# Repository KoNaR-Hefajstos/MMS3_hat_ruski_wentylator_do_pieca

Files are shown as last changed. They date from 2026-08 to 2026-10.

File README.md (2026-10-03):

# Hat ruski wentylator do pieca

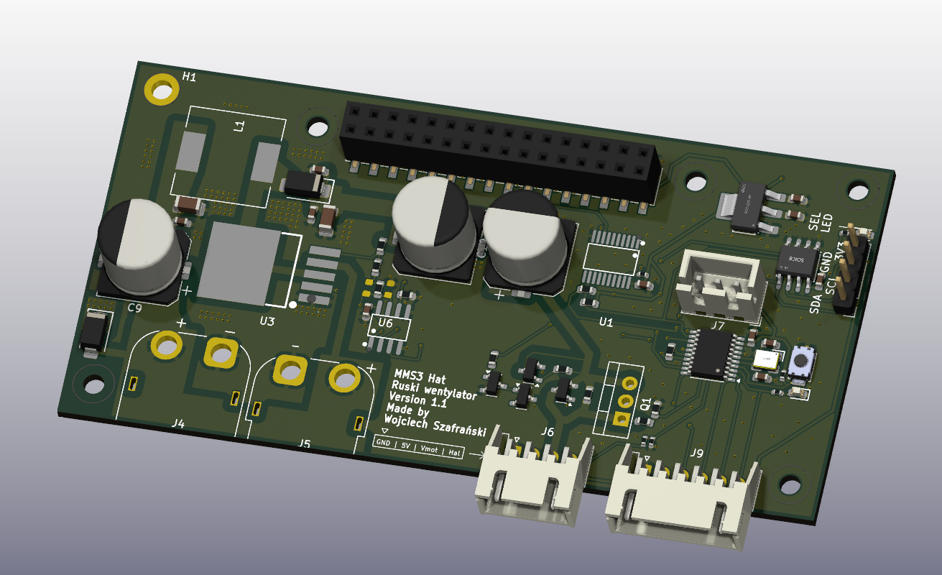
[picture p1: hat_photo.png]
zdjecie


## Sekcja 1: Dokumentacja Hat'a

### Krótki opis projektu
Dedykowany moduł sterujący przeznaczony do obsługi ruskiego wentylatora pieca . Urządzenie bazuje na mikrokontrolerze **CH32V003**, który realizuje zadania regulacji napięcia zasilania silnika, sterowania kluczem PWM, pomiaru prędkości obrotowej z czujnika Halla i reguluje prędkość obrotową przy użyciu regulatora PID.

Moduł wyposażono w przetwornicę podwyższającą (Boost) sterowaną cyfrowym potencjometrem MCP4161 oraz stopień wykonawczy typu **high-side switch** oparty na tranzystorze PMOS.

Komunikacja po I2C

### Zgodność ze standardem ChainBus

* ✅  Używa złącza ChainBus, nie zmienia jego miejsca ani pinoutu.
* ✅  Używa wyłącznie interfejsów I2C, SPI lub UART i nie inicjuje samodzielnie nowych transmisji (Nie jest master'em I2C albo SPI).
* ✅  Spełnia wymagania mechaniczne standardu (wymiary PCB, rozstaw otworów).
* ✅  Pobiera maksymalny prąd zgodny z ilością na jednego hat'a
* ❌ Obsługuje napięcie wejściowe BRD_VIN do wartości 48V. ---> napięcie wejściowe max 40V. Zawsze podaje napięcie wejściowe na wyjście wentylatora (J6 pin 3)

### Komunikacja i adresowanie

#### Adresacja I2C
Komunikacja z płytą główną ChainBus odbywa się za pośrednictwem magistrali I2C podłączonej do mikrokontrolera CH32V003.

| Układ (IC) | Funkcja | Adres I2C (7-bit) |
| :--- | :--- | :---: |
| **CH32V003** | Mikrokontroler (zarządzanie modułem) | *Konfigurowalny w sofcie* |

### Pinout mikrokontrolera CH32V003

| Pin MCU | Nazwa sygnału | Kierunek | Opis funkcjonalny |
| :--- | :--- | :---: | :--- |
| **PC0** | `PWM_GATE` | Wyjście  | Sterowanie bramką PMOS (high-side switch) |
| **PC1** | `SDA` | Wej/Wyj  | Linia danych magistrali I2C (ChainBus) |
| **PC2** | `SCL` | Wejście  | Linia zegarowa magistrali I2C (ChainBus) |
| **PC3** | `BOOST_EN` | Wyjście  | Włączenie przetwornicy Boost (`1` = ON, `0` = OFF) |
| **PC4** | `V_MONITOR` | Wejście  | Pomiar ADC napięcia silnika (dzielnik 36k / 2k) |
| **PC5** | `SPI_SCK` | Wyjście  | Zegar SPI do potencjometru MCP4161 |
| **PC6** | `SPI_MOSI` | Wyjście  | Dane wyjściowe SPI do potencjometru MCP4161 |
| **PC7** | `SPI_MISO` | Wejście  | Dane wejściowe SPI z potencjometru MCP4161 |
| **PD0** | `HALL_INPUT`  | Wejście  | Sygnał z czujnika Halla wentylatora |
| **PD2** | `SPI_CS_POT`  | Wyjście  | Wybór układu (Chip Select) dla MCP4161 |
| **PD3** | `GPIO_PD3` | Wej/Wyj  | Wolny pin GPIO wyprowadzony na złącze J9 |
| **PD4** | `GPIO_PD4` | Wej/Wyj  | Wolny pin GPIO wyprowadzony na złącze J9 |
| **PD5** | `USART_TX` | Wyjście  | Port szeregowy TX (debugowanie, złącze J9) |
| **PD6** | `USART_RX` | Wejście  | Port szeregowy RX (złącze J9) |

---

### Pinout złączy zewnętrznych

#### J6 — Złącze wentylatora pieca
Złącze przeznaczone do bezpośredniego podłączenia ruskiego wentylatora.

| Pin złącza | Kolor przewodu z wentlatora | Nazwa sygnału | Opis |
| :---: | :--- | :--- | :--- |
| **1** | Czarny | `GND` | Wspólna masa układu |
| **2** | Brązowy | `5V` | Zasilanie układu Halla wentylatora |
| **3** | Niebieski | `VCC_MOTOR` | Napięcie zasilające silnik wentylatora |
| **4** | Biały/Żółty | `HALL` | Wyjście czujnika Halla (sprzężenie zwrotne obrotów) |

#### J9 — Złącze wolnych pinów mcu

| Pin złącza | Sygnał | Opis |
| :---: | :----- | :--- |
| **1** | `GND`  | Masa układu |
| **2** | `3V3`  | Zasilanie logiki 3.3V |
| **3** | `PD3`  | Wolny port GPIO |
| **4** | `PD4`  | Wolny port GPIO |
| **5** | `PD5`  | GPIO + Wyjście USART TX |
| **6** | `PD6`  | GPIO + Wejście USART RX |

---

### Konfiguracja i zasada działania stopni wykonawczych

#### 1. Regulacja Napięcia (Przetwornica Boost)
Napięcie zasilania silnika jest generowane przez przetwornicę podwyższającą z poziomu wejściowego 12V. Napięcie wyjściowe regulowane jest przy użyciu potencjometru cyfrowego MCP4161 (5kΩ) działającego jako rezystor nastawny w feedback'u regulatora . Wyjście `P0B` podłączone jest z jednej strony, natomiast wyjścia `P0W` i `P0A` są ze sobą zwarte z drugiej.

Napięcie wyjściowe definiuje zależność:
$$U_{out} = 1.25 \times \left(1 + \frac{50\text{k}\Omega}{1.22\text{k}\Omega + R_{trim}}\right)$$

*   **⚠️ KRYTYCZNE OGRANICZENIE BEZPIECZEŃSTWA:** Mimo teoretycznego zakresu regulacji przetwornicy od 12V do 60V, **maksymalne dopuszczalne napięcie robocze wynosi 24V**. Przekroczenie tego progu spowoduje nieodwracalne uszkodzenie wentylatora, kondensatorów filtrujących oraz stopnia high-side switch. (24V silnika, a ~40V kondensatorów)
*   **Procedura bezpiecznego startu:** Przy każdym uruchomieniu mikrokontrolera, oprogramowanie musi natychmiast ustawić potencjometr MCP4161 na **maksymalną rezystancję (5kΩ)**, co wymusza minimalne napięcie startowe (ok. 11.3V). Dodatkowo, przetwornica Boost oraz klucz PWM muszą być domyślnie wyłączone (`BOOST_EN` = `0`, `PWM_GATE` = `0`).
*   **Charakterystyka Boost:** Nawet w stanie wyłączonym (`BOOST_EN` = `0`), napięcie wejściowe 12V będzie stale obecne na wyjściu przetwornicy.

#### 2. Bonusowy Stopień wykonawczy (High-Side Switch PMOS)
Sterowanie dopływem prądu z przetwornicy do silnika wentylatora odbywa się za pomocą klucza high-side switch opartego na tranzystorze PMOS.

*   **Konfiguracja domyślna (Bypass):** Na płycie fabrycznie wlutowany jest rezystor **R6**, który zwiera (pomija) tranzystor PMOS. W tym trybie silnik zasilany jest stale bezpośrednio z wyjścia przetwornicy Boost, a regulacja obrotów odbywa się wyłącznie poprzez zmianę jej napięcia wyjściowego.
*   **Konfiguracja zaawansowana (Sterowanie PWM):** W celu sterowania silnikiem za pomocą cięcia prądu sygnałem PWM z pinu `PC0` mikrokontrolera, należy **odlutować rezystor R6**.
*   **Element wykonawczy:** Na płycie domyślnie znajduje się tranzystor PMOS **AO3401A** (obudowa SOT-23, parametry: 30V, 4A), który jest w pełni wystarczający do obsługi docelowego wentylatora piecowego. Na laminacie pozostawiono jednak alternatywne, wolne miejsce na montaż mocniejszego tranzystora w obudowie **TO-220** na wypadek nietypowych modyfikacji.

#### A po ludzku
* Masz wentlator, sterujesz jego prękością dając mu różne napięcie i/lub PWM
* Napięciem sterujesz przez potencjometr cyfrowy
* PWM przez high side switch (który jest domyślnie z'bypass'owany czyli trzeba wylutować rezystor żeby go użyć)
* Przetworke możesz właczyć/wyłączyć, ale zawsze daje VIN na wyjście silnika
* Prędkość obrotową wentylatora możesz odczytać przez częstotliwosć impulsów na czujnika halla
* A napięcie wyjściowe przetworki jest po dzielniku napięć na pin'ie PC4 (dzielnik dzieli VCC silnika przez 18)

---

### Gotowe arkusze hierarchiczne
W projekcie zaprojektowano i użyto następujących arkuszy hierarchicznych:
* **CH32v003** – Schemat mikrokontrolera głównego wraz z elementami pasywnymi i złączem programowania
* **Boost converter** – Układ regulowanej przetwornicy podwyższającej napięcie z 12V na zakres do ~60V sterowanej cyfrowym potencjometrem MCP4161.
* **High side switch** – Blok High-side switch'a na PMOS (AO3401A) sterowanego sygnałem PWM z układem typu totem pole do drive'owania bramki
---

## Sekcja 2: Specyfikacja standardu ChainBus

### Architektura i łączenie modułów
Standard ChainBus umożliwia modułowe łączenie hatów. Na jednym MMS3 można zamontować pionowo **do 8 hat'ów**. Połączenie realizowane jest poprzez wpięcie złącza męskiego kolejnego hat'a w złącze żeńskie poprzedniego

### Komunikacja i sterowanie
Magistrala ChainBus jest w pełni cyfrowa. Płyta główna nie steruje bezpośrednio sygnałami ogólnego przeznaczenia (GPIO) na poszczególnych hat'ach. Wszelkie operacje (np. obsługa diod LED, odczyt krańcówek, generowanie sygnałów PWM) muszą być realizowane przez dedykowane układy scalone (np. ekspandery portów, sterowniki) komunikujące się przez interfejsy systemowe.

*Przykład:*
`MCU` $\rightarrow$ `Expander GPIO po I2C` $\rightarrow$ `Dioda LED`

Wybór aktywnego modułu realizowany jest przez układ przełącznika magistrali (bus switch) na płycie głównej. Dzięki temu linie I2C, SPI i UART są niezależne dla każdego hat'a (brak konfliktów adresów I2C między różnymi hatami).
* **Identyfikacja:** Każdy moduł powinien posiadać pamięć EEPROM na magistrali I2C w celu identyfikacji płyty przez system - układ M24C64-W skonfigurowany na adres `1010000` przy liniach adresowych A0, A1, A2 zwartych do masy.

### Zasilanie
Złącze ChainBus dostarcza następujące linie zasilania:

| Magistrala zasilania | Napięcie znamionowe | Maksymalny prąd (łączny dla 8 hatów) | Szacowany prąd na jeden hat |
| :--- | :---: | :---: | :---: |
| **5V** | 5.0 V | 1.0 A | 125 mA |
| **12V stby** | 12.0 V | 0.5 A | 65 mA |
| **BRD_VIN** | 12.0 V – 48.0 V | 1.5 A | 185 mA |

*   Komponenty podłączone do linii `BRD_VIN` muszą być przystosowane do pracy z napięciem od 12V do **48 V**.
*   W przypadku zapotrzebowania na wyższą moc, dopuszczalne jest zastosowanie dodatkowego złącza zasilania XT60 (obciążalność do ok. 60 A).

### Wymagania mechaniczne i złącza
* **Wymiary PCB:** Niedozwolona jest zmiana obrysu płytki oraz położenia otworów montażowych, aby zachować kompatybilność mechaniczną.
* **Pozycjonowanie złączy ChainBus:** Położenie złącza standardu 2x16 SMD (raster 2.54 mm) musi być zgodne z szablonem. Złącze żeńskie montowane jest na stronie FRONT, natomiast złącze męskie na stronie BACK.
* **Interfejsy zewnętrzne:** Złącza wejścia/wyjścia (domyślnie standard JST-XH 2.5 mm o obciążalności do 3 A) oraz opcjonalne złącze XT60 powinny być umieszczone przy dolnej krawędzi płytki. Elementy regulacyjne i sygnalizacyjne (potencjometry, przełączniki, diody LED) należy lokalizować przy prawej krawędzi płytki.
* **Komponenty** Wszystkie komponenty powinny być na stronie front płytki żeby nie haczyły o elementy ze wcześniejszego hat'a

---

## Sekcja 3: Licencje

### Licencje projektu

*   **PCB:** CERN-OHL-P
*   **Software:** MIT License

[Template](https://github.com/KoNaR-Hefajstos/MMS3_hat_templates/) jest na licencji CC0 1.0 Universal. **Reszta projektu nie jest na tej licencji**

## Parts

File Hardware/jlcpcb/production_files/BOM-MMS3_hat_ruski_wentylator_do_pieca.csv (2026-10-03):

Comment | Designator | Footprint | LCSC | Quantity
0Ω | R18,R6 | R_0603 | C21189 | 2
100nF | C1,C2,C4,C6 | C_0603 | C14663 | 4
10kΩ | R12,R19,R24 | R_0402 | C25744 | 3
10kΩ | R2,R3 | R_0603 | C25804 | 2
10uF | C14,C15 | C_1206 | C13585 | 2
10uF | C16,C18 | C_0603 | C19702 | 2
12pF | C3,C5 | C_0603 | C38523 | 2
15kΩ | R23 | R_0402 | C25756 | 1
1kΩ | R16,R17,R5,R7 | R_0603 | C21190 | 4
1uF | C10,C11,C17 | C_0603 | C15849 | 3
220Ω | R28 | R_0603 | C22962 | 1
2kΩ | R20 | R_0603 | C22975 | 1
330Ω | R1,R13 | R_0402 | C25104 | 2
36kΩ | R4 | R_0603 | C23147 | 1
56kΩ | R14 | R_0603 | C23206 | 1
AMS1117 | U4 | SOT-223-3_L6.5-W3.4-P2.30-LS7.0-BR | C6186 | 1
AO3401A | Q10 | Q_SOT-23 | C15127 | 1
M24C64 | U2 | SOIC-8_L5.0-W4.0-P1.27-LS6.0-BL | C79988 | 1
M7 | D1 | D_SMA | C95872 | 1
MCP4161-502E/SN | U6 | SOIC-8_L4.9-W3.9-P1.27-LS6.0-BL | C636080 | 1
MMBT5401 200-300 | Q11 | Q_SOT-23 | C8326 | 1
MMBT5551 200-300 | Q12,Q9 | Q_SOT-23 | C2145 | 2
Red | D3,D5 | D_0603 | C2286 | 2
SN74CB3Q3245PWR | U1 | TSSOP-20_L6.5-W4.4-P0.65-LS6.4-BL | C470961 | 1
SS54 | D2 | D_SMA | C22452 | 1
Tactile Button, 160gf | S1 | SW_TS-1088-AR02016 | C720477 | 1
Whatever the chinese man has (preferably 220uF) | C12,C13,C9 | CP_Elec_10x10 | C178727 | 3
X322525MOB4SI | X2 | OSC-SMD_4P-L3.2-W2.5-BL | C9006 | 1
XL6019E1 | U3 | TO-263-5_L10.2-W9.9-P1.70-LS14.4-TL | C73018 | 1
Conn_01x06_Socket | J9 | JST_XH_S6B-XH-A_1x06_P2.50mm_Horizontal |  | 1
Program | J7 | JST_XH_B3B-XH-A_1x03_P2.50mm_Vertical |  | 1
Conn_01x04_Socket | J6 | JST_XH_S4B-XH-A_1x04_P2.50mm_Horizontal |  | 1
Chainbus Out | J2 | PinSocket_2x16_P2.54mm_Vertical_SMD |  | 1
PMOS | Q1 | TO-220-3_Vertical |  | 1
Conn_01x04_Pin | J3 | PinHeader_1x04_P2.54mm_Vertical |  | 1
47uH 5A | L1 | L_12x12mm_H6mm |  | 1
CH32V003FxPx | U5 | TSSOP-20_4.4x6.5mm_P0.65mm |  | 1
TestPoint | TP5 | TestPoint_Pad_D1.5mm |  | 1
Chainbus in | J1 | PinHeader_2x16_P2.54mm_Vertical_SMD |  | 1
TestPoint | TP4 | TestPoint_Pad_D1.5mm |  | 1
TestPoint | TP6 | TestPoint_Pad_D1.5mm |  | 1

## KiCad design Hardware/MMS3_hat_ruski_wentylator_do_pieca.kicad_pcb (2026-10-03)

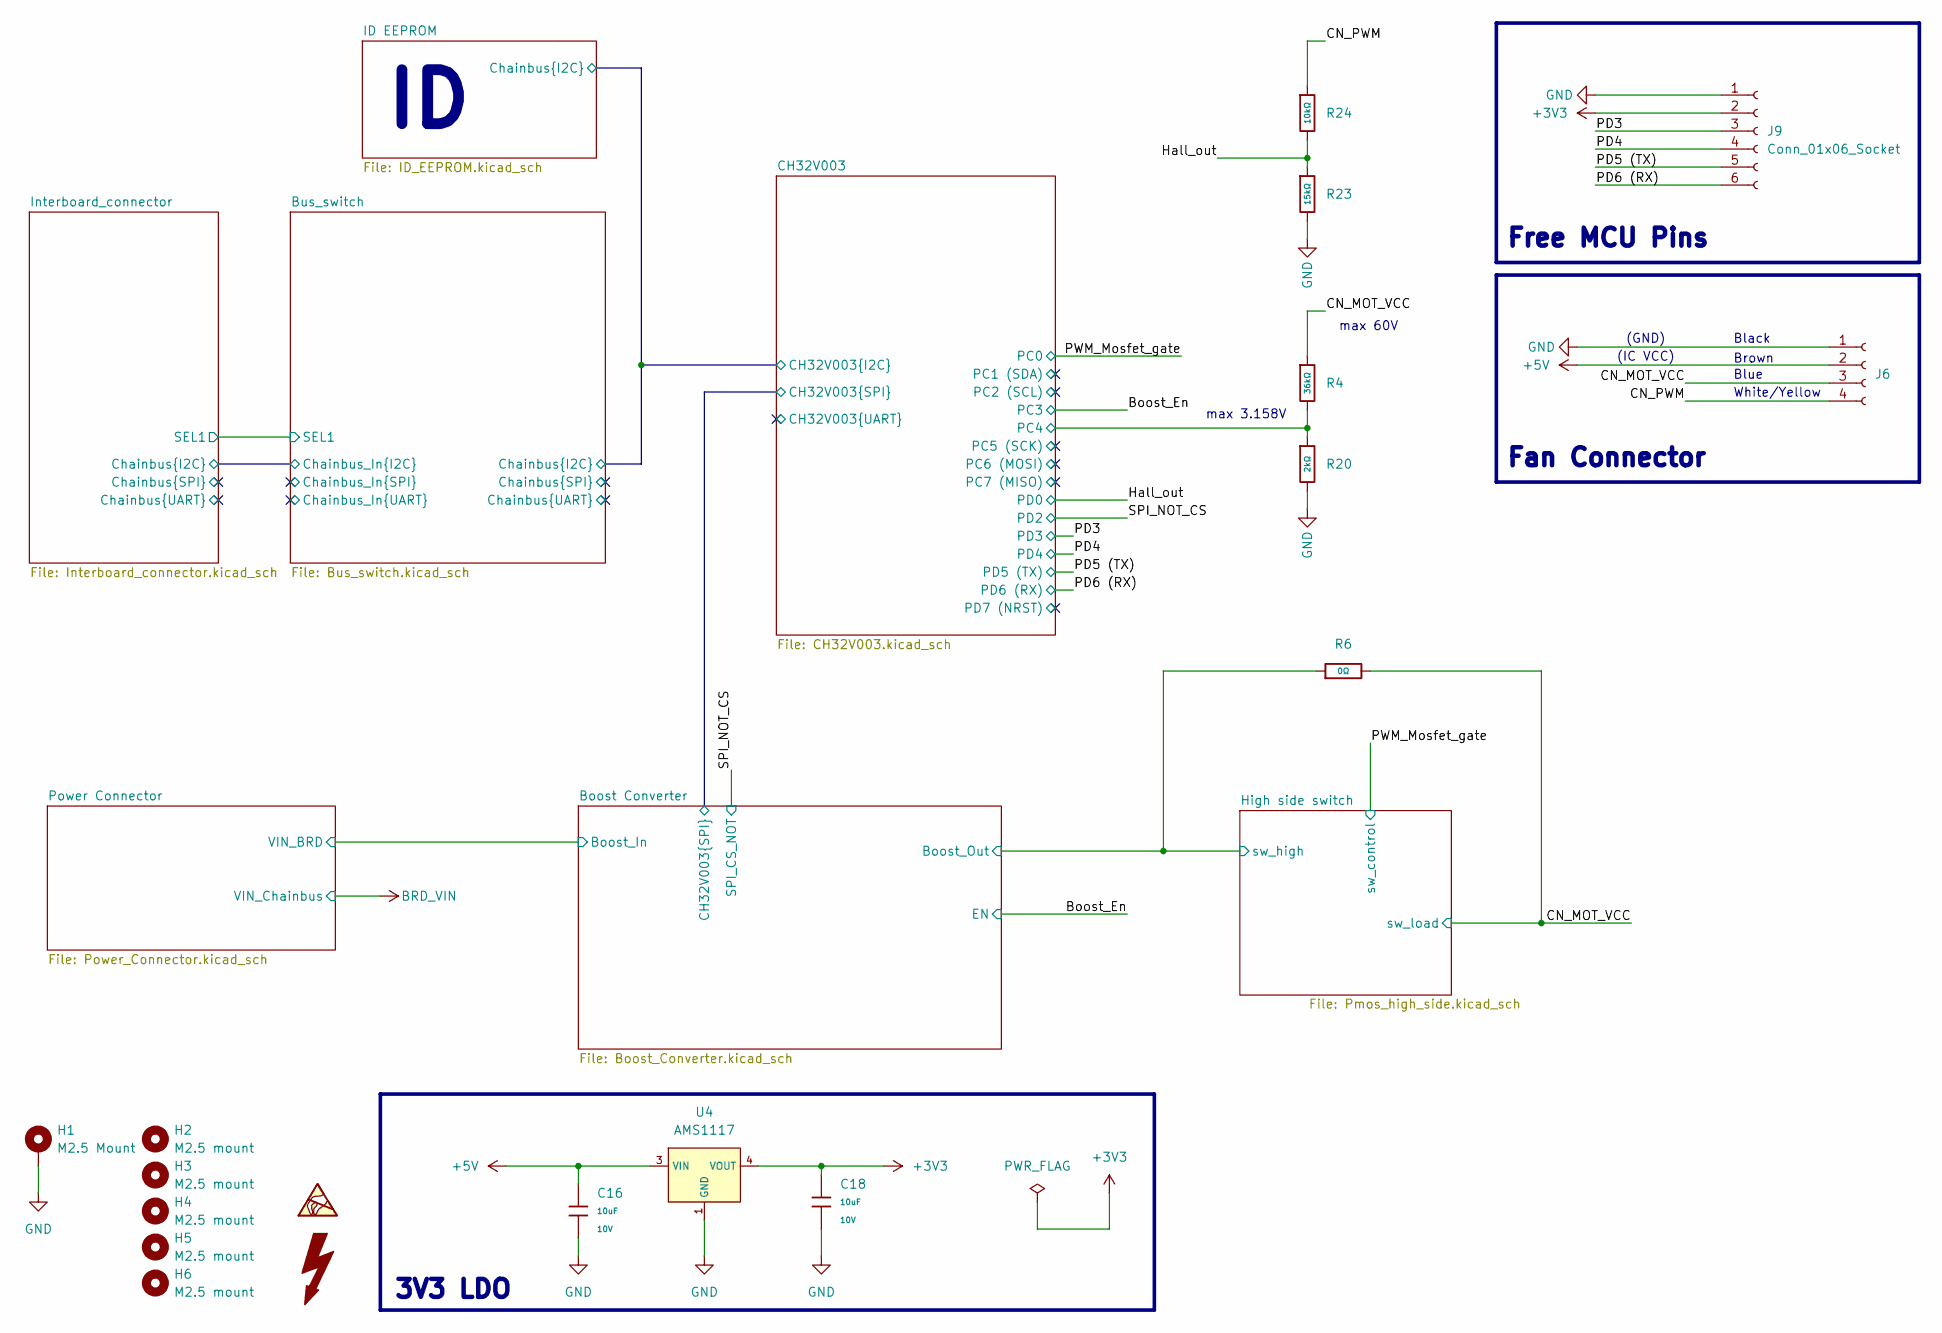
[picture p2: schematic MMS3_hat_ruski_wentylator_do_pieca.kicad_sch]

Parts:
C16, C18: 10uF; C_0603; Voltage Rated 10V; Tolerance ±10%; Part CL10A106KP8NNNC; LCSC C19702
H1: M2.5 Mount; MountingHole_2.7mm_M2.5_DIN965_Pad_TopOnly
H2, H3, H4, H5, H6: M2.5 mount; MountingHole_2.7mm_M2.5
J6: Conn_01x04_Socket; JST_XH_S4B-XH-A_1x04_P2.50mm_Horizontal
J9: Conn_01x06_Socket; JST_XH_S6B-XH-A_1x06_P2.50mm_Horizontal
R4: 36kΩ; R_0603; Overload Voltage (Max) 75V; Tolerance ±1%; Part 0603WAF3602T5E; LCSC C23147
R6: 0Ω; R_0603; Overload Voltage (Max) 75V; Tolerance ±1%; Part 0603WAF0000T5E; LCSC C21189
R20: 2kΩ; R_0603; Overload Voltage (Max) 75V; Tolerance ±1%; Part 0603WAF2001T5E; LCSC C22975
R23: 15kΩ; R_0402; Overload Voltage (Max) 50V; Tolerance ±1%; Part 0402WGF1502TCE; LCSC C25756
R24: 10kΩ; R_0402; Overload Voltage (Max) 50V; Tolerance ±1%; Part 0402WGF1002TCE; LCSC C25744
U4: AMS1117; SOT-223-3_L6.5-W3.4-P2.30-LS7.0-BR; Output Voltage 3.3V; Dropout Voltage 1.3V@(800mA); Part AMS1117-3.3; LCSC C6186

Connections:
+3V3: C18.1, J9.2, U4.2 (VOUT), U4.4 (VOUT); also elsewhere on the board
+5V: C16.1, J6.2, U4.3 (VIN); also elsewhere on the board
/Boost Converter/Boost_Out: R6.1; also elsewhere on the board
/CH32V003/PC4: R4.2, R20.1; also elsewhere on the board
/CN_MOT_VCC: J6.3, R4.1, R6.2; also elsewhere on the board
/CN_PWM: J6.4, R24.1
/Hall_out: R23.1, R24.2; also elsewhere on the board
/PD3: J9.3; also elsewhere on the board
/PD4: J9.4; also elsewhere on the board
/PD5 (TX): J9.5; also elsewhere on the board
/PD6 (RX): J9.6; also elsewhere on the board
GND: C16.2, C18.2, H1.1 (1_1), J6.1, J9.1, R20.2, R23.2, U4.1 (GND); also elsewhere on the board

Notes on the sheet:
(IC VCC)
Blue
max 60V
Fan Connector
White/Yellow
(GND)
3V3 LDO
Free MCU Pins
max 3.158V
Brown
Black

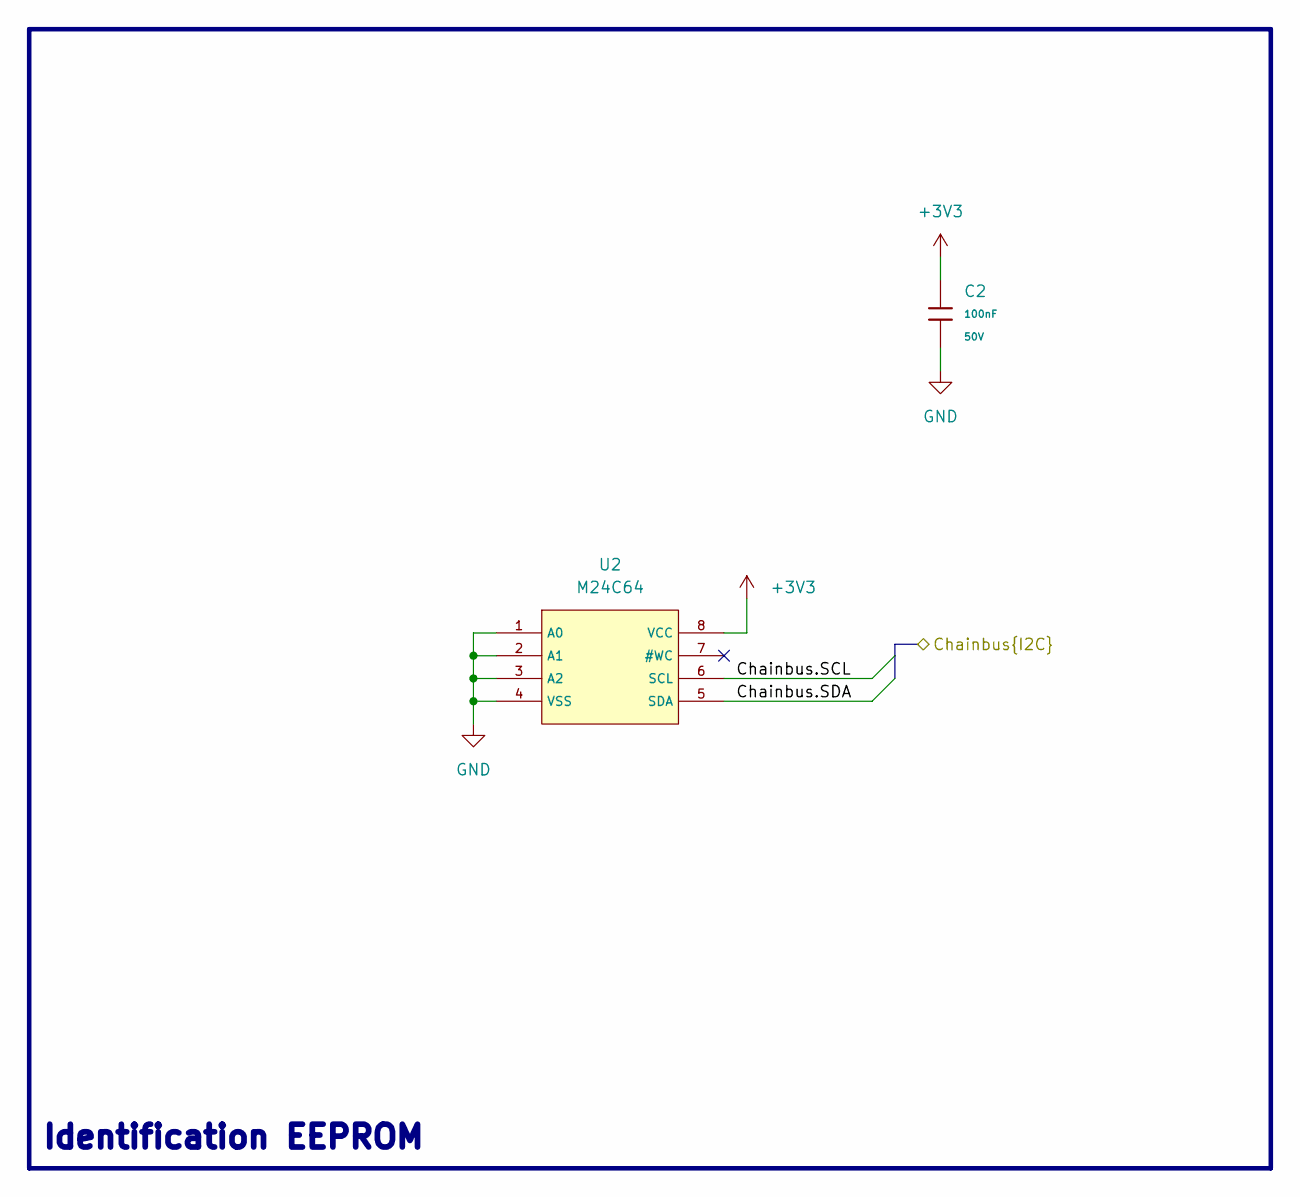
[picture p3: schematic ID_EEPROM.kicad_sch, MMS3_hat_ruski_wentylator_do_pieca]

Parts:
C2: 100nF; C_0603; Voltage Rated 50V; Tolerance ±10%; Part CC0603KRX7R9BB104; LCSC C14663
U2: M24C64; SOIC-8_L5.0-W4.0-P1.27-LS6.0-BL; Supply Voltage 1.8V~5.5V; Part M24C64-RMN6TP; LCSC C79988

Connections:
+3V3: C2.1, U2.8 (VCC); also elsewhere on the board
/Bus_switch/Chainbus.SCL: U2.6 (SCL); also elsewhere on the board
/Bus_switch/Chainbus.SDA: U2.5 (SDA); also elsewhere on the board
GND: C2.2, U2.1 (A0), U2.2 (A1), U2.3 (A2), U2.4 (VSS); also elsewhere on the board

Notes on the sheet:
Identification EEPROM

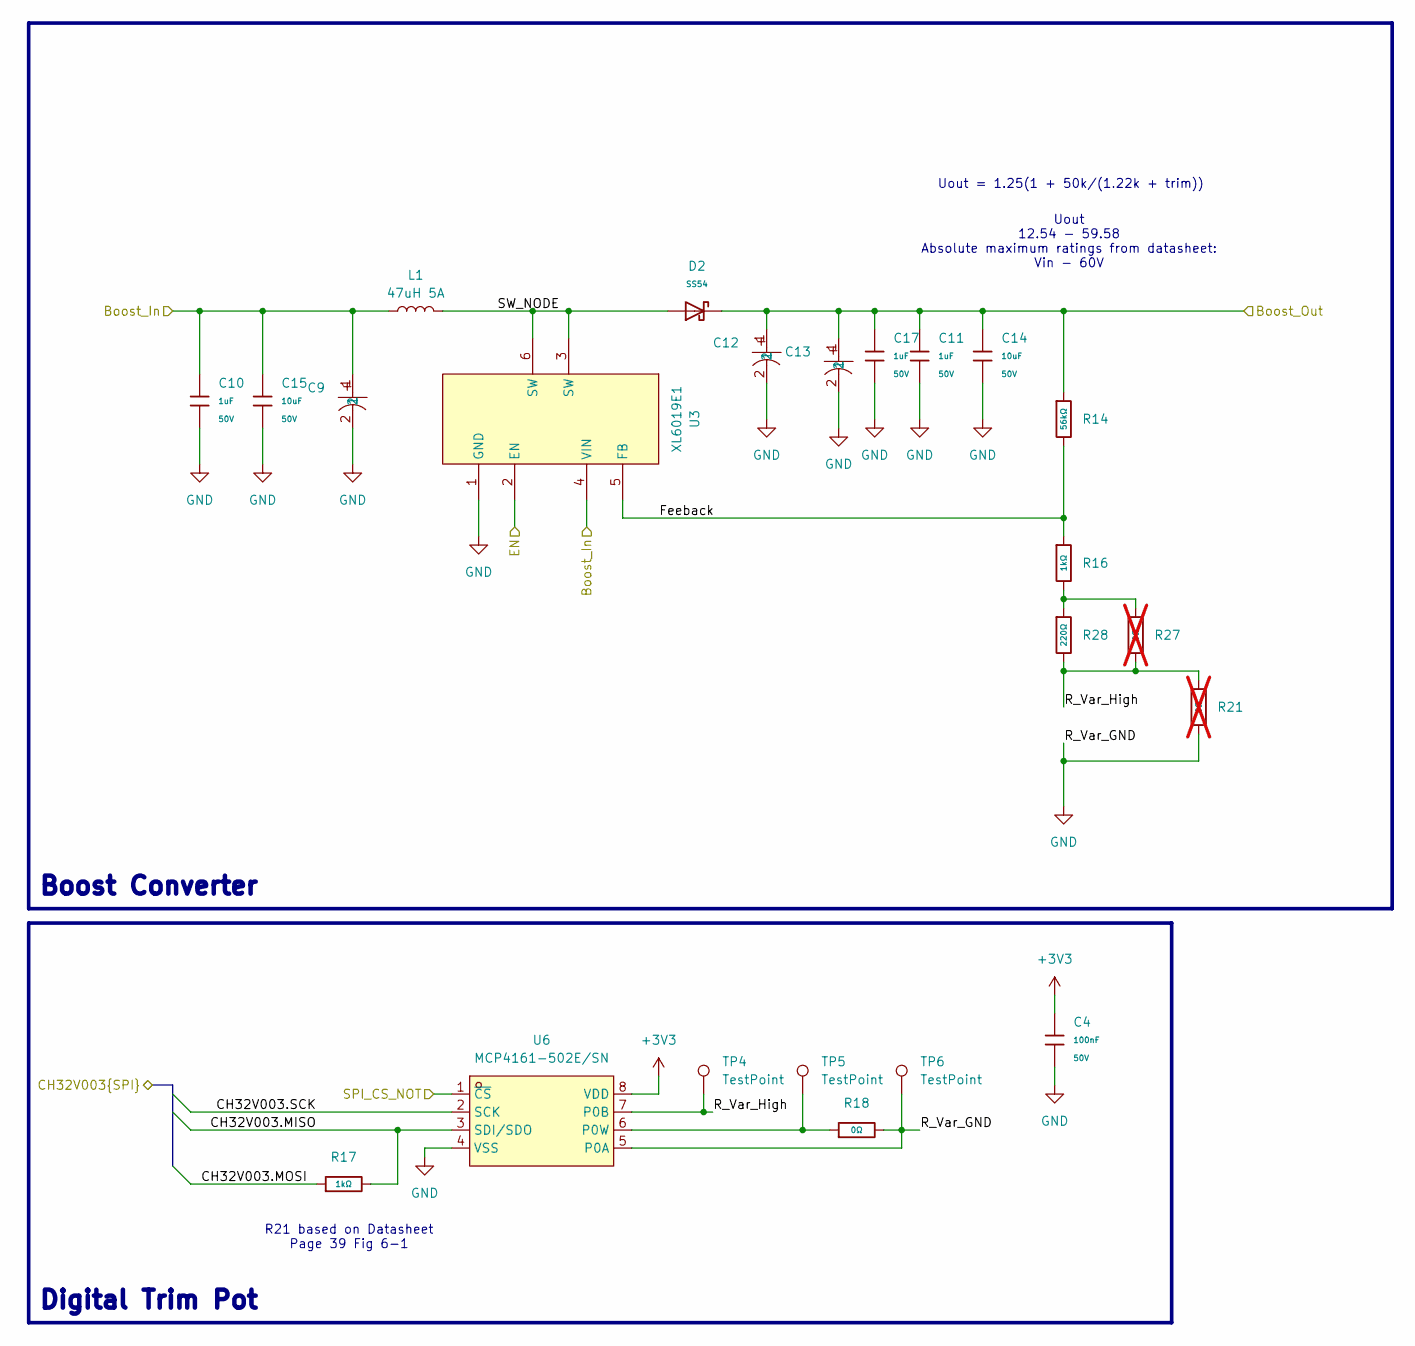
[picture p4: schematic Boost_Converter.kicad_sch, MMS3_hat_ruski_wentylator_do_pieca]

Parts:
C4: 100nF; C_0603; Voltage Rated 50V; Tolerance ±10%; Part CC0603KRX7R9BB104; LCSC C14663
C9, C12, C13: Whatever the chinese man has (preferably 220uF); CP_Elec_10x10; MPN EEVFK1J221Q; LCSC Part C178727
C10, C11, C17: 1uF; C_0603; Voltage Rated 50V; Tolerance ±10%; Part CL10A105KB8NNNC; LCSC C15849
C14, C15: 10uF; C_1206; Voltage Rated 50V; Tolerance ±10%; Part CL31A106KBHNNNE; LCSC C13585
D2: SS54; D_SMA; Forward Voltage (Vf@If) 550mV@5A; Reverse Voltage (Vr) 40V; Part SS54; LCSC C22452
L1: 47uH 5A; L_12x12mm_H6mm
R14: 56kΩ; R_0603; Overload Voltage (Max) 75V; Tolerance ±1%; Part 0603WAF5602T5E; LCSC C23206
R16, R17: 1kΩ; R_0603; Overload Voltage (Max) 75V; Tolerance ±1%; Part 0603WAF1001T5E; LCSC C21190
R18: 0Ω; R_0603; Overload Voltage (Max) 75V; Tolerance ±1%; Part 0603WAF0000T5E; LCSC C21189
R21, R27: 0Ω; R_0603; Overload Voltage (Max) 75V; Tolerance ±1%; Part 0603WAF0000T5E; LCSC C21189; not fitted
R28: 220Ω; R_0603; Overload Voltage (Max) 75V; Tolerance ±1%; Part 0603WAF2200T5E; LCSC C22962
TP4, TP5, TP6: TestPoint; TestPoint_Pad_D1.5mm
U3: XL6019E1; TO-263-5_L10.2-W9.9-P1.70-LS14.4-TL; MPN XL6019E1; LCSC Part C73018
U6: MCP4161-502E/SN; SOIC-8_L4.9-W3.9-P1.27-LS6.0-BL; MPN MCP4161-502E/SN; LCSC Part C636080

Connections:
+3V3: C4.1, U6.8 (VDD); also elsewhere on the board
/Boost Converter/Boost_In: C9.1, C10.1, C15.1, L1.1, U3.4 (VIN); also elsewhere on the board
/Boost Converter/Boost_Out: C11.1, C12.1, C13.1, C14.1, C17.1, D2.1, R14.1; also elsewhere on the board
/Boost Converter/CH32V003.MISO: R17.2, U6.3 (SDI/SDO); also elsewhere on the board
/Boost Converter/CH32V003.MOSI: R17.1; also elsewhere on the board
/Boost Converter/CH32V003.SCK: U6.2 (SCK); also elsewhere on the board
/Boost Converter/Feeback: R14.2, R16.1, U3.5 (FB)
/Boost Converter/R_Var_High: R21.2, R27.1, R28.2, TP4.1 (1_1), U6.7 (P0B)
/Boost Converter/SW_NODE: D2.2, L1.2, U3.3 (SW), U3.6 (SW)
/Boost_En: U3.2 (EN); also elsewhere on the board
/SPI_NOT_CS: U6.1 (~CS); also elsewhere on the board
GND: C4.2, C9.2, C10.2, C11.2, C12.2, C13.2, C14.2, C15.2, C17.2, R18.2, R21.1, TP6.1 (1_1), U3.1 (GND), U6.4 (VSS), U6.5 (P0A); also elsewhere on the board
unnamed: R16.2, R27.2, R28.1
unnamed: R18.1, TP5.1 (1_1), U6.6 (P0W)

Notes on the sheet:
Uout = 1.25(1 + 50k/(1.22k + trim))
Boost Converter
Uout 12.54 - 59.58 Absolute maximum ratings from datasheet: Vin - 60V
R21 based on Datasheet Page 39 Fig 6-1
Digital Trim Pot

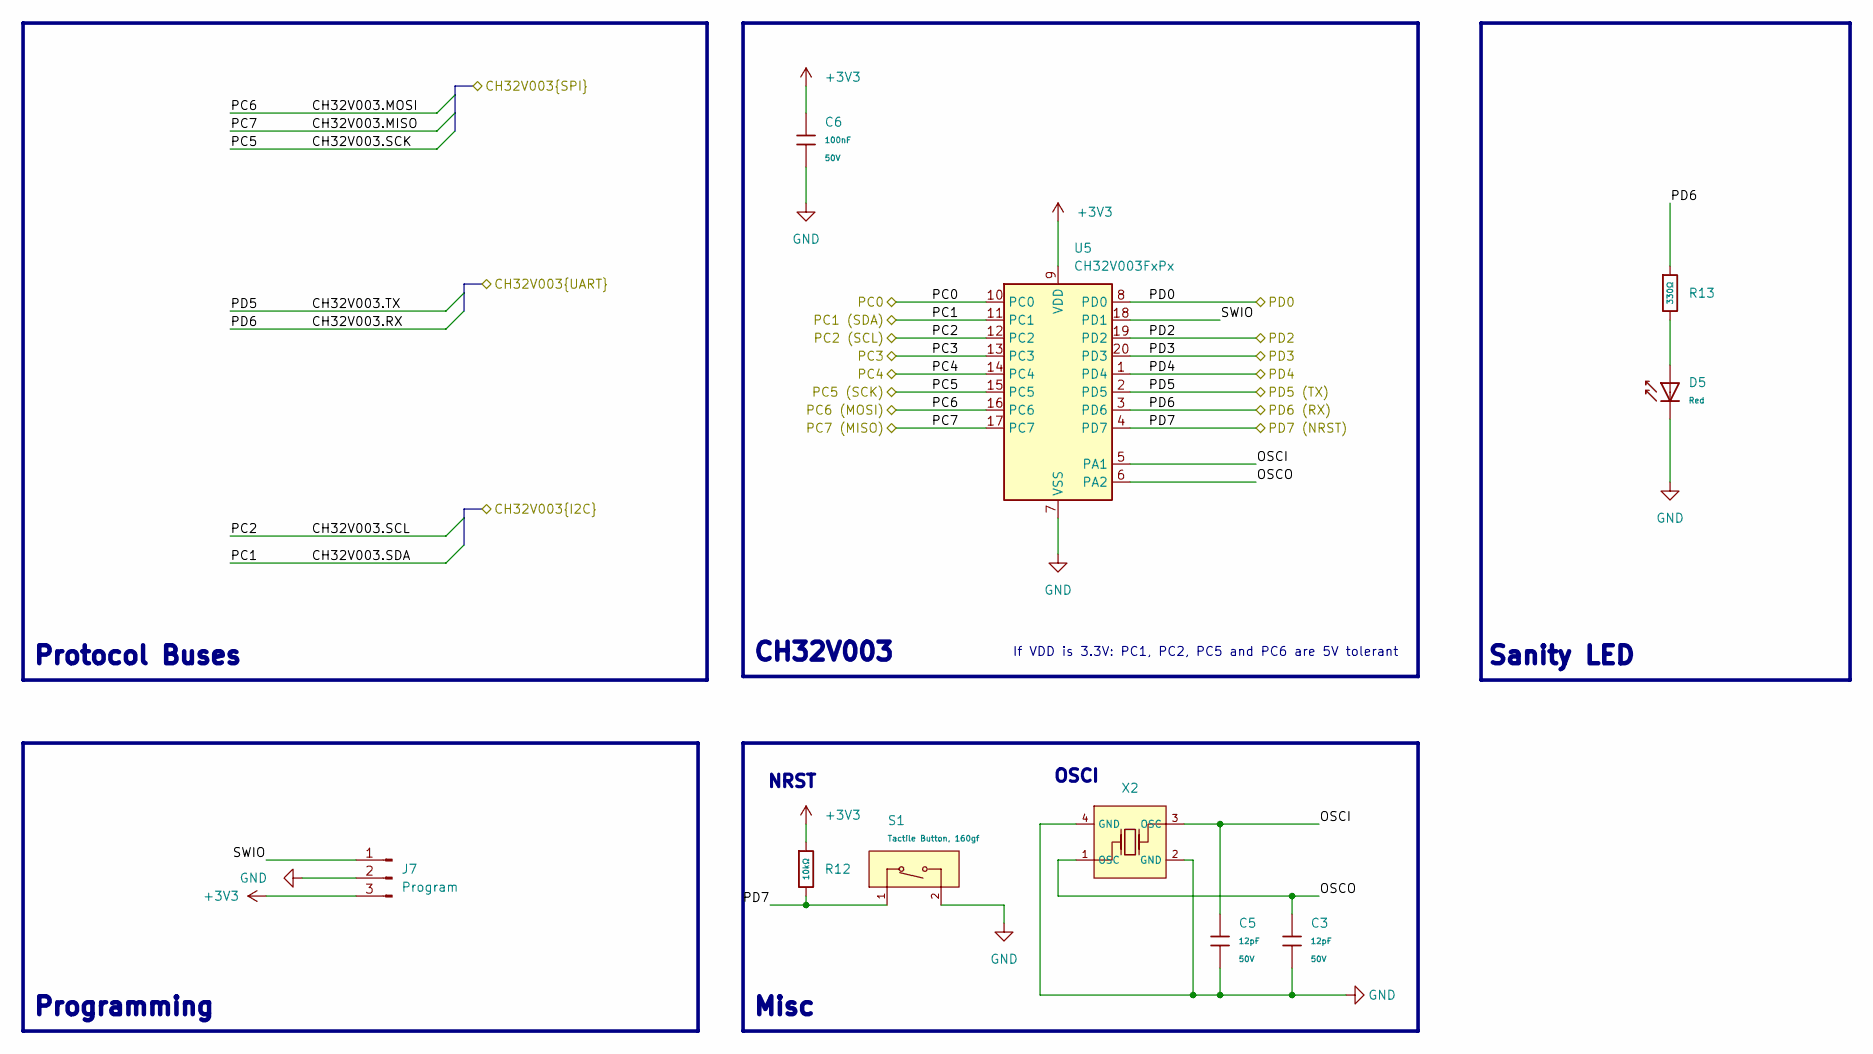
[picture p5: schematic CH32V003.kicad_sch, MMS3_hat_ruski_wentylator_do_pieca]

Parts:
C3, C5: 12pF; C_0603; Voltage Rated 50V; Tolerance ±5%; Part CL10C120JB8NNNC; LCSC C38523
C6: 100nF; C_0603; Voltage Rated 50V; Tolerance ±10%; Part CC0603KRX7R9BB104; LCSC C14663
D5: Red; D_0603; Part KT-0603R; LCSC C2286
J7: Program; JST_XH_B3B-XH-A_1x03_P2.50mm_Vertical
R12: 10kΩ; R_0402; Overload Voltage (Max) 50V; Tolerance ±1%; Part 0402WGF1002TCE; LCSC C25744
R13: 330Ω; R_0402; Overload Voltage (Max) 50V; Tolerance ±1%; Part 0402WGF3300TCE; LCSC C25104
S1: Tactile Button, 160gf; SW_TS-1088-AR02016; Voltage Rating (Dc) 12V; Part TS-1088-AR02016; LCSC C720477
U5: CH32V003FxPx; TSSOP-20_4.4x6.5mm_P0.65mm
X2: X322525MOB4SI; OSC-SMD_4P-L3.2-W2.5-BL; Frequency Tolerance ±10ppm; Part X322525MOB4SI; LCSC C9006

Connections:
+3V3: C6.1, J7.3, R12.1, U5.9 (VDD); also elsewhere on the board
/Boost Converter/CH32V003.MISO: U5.17 (PC7); also elsewhere on the board
/Boost Converter/CH32V003.MOSI: U5.16 (PC6); also elsewhere on the board
/Boost Converter/CH32V003.SCK: U5.15 (PC5); also elsewhere on the board
/Boost_En: U5.13 (PC3); also elsewhere on the board
/Bus_switch/Chainbus.SCL: U5.12 (PC2); also elsewhere on the board
/Bus_switch/Chainbus.SDA: U5.11 (PC1); also elsewhere on the board
/CH32V003/OSCI: C5.1, U5.5 (PA1), X2.3 (OSC)
/CH32V003/OSCO: C3.1, U5.6 (PA2), X2.1 (OSC)
/CH32V003/PC4: U5.14 (PC4); also elsewhere on the board
/CH32V003/PD7: R12.2, S1.1 (A), U5.4 (PD7)
/CH32V003/SWIO: J7.1, U5.18 (PD1)
/Hall_out: U5.8 (PD0); also elsewhere on the board
/PD3: U5.20 (PD3); also elsewhere on the board
/PD4: U5.1 (PD4); also elsewhere on the board
/PD5 (TX): U5.2 (PD5); also elsewhere on the board
/PD6 (RX): R13.1, U5.3 (PD6); also elsewhere on the board
/PWM_Mosfet_gate: U5.10 (PC0); also elsewhere on the board
/SPI_NOT_CS: U5.19 (PD2); also elsewhere on the board
GND: C3.2, C5.2, C6.2, D5.1, J7.2, S1.2 (B), U5.7 (VSS), X2.2 (GND), X2.4 (GND); also elsewhere on the board
unnamed: D5.2, R13.2

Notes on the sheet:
NRST
Sanity LED
If VDD is 3.3V: PC1, PC2, PC5 and PC6 are 5V tolerant
CH32V003
OSCI
Protocol Buses
Misc
Programming

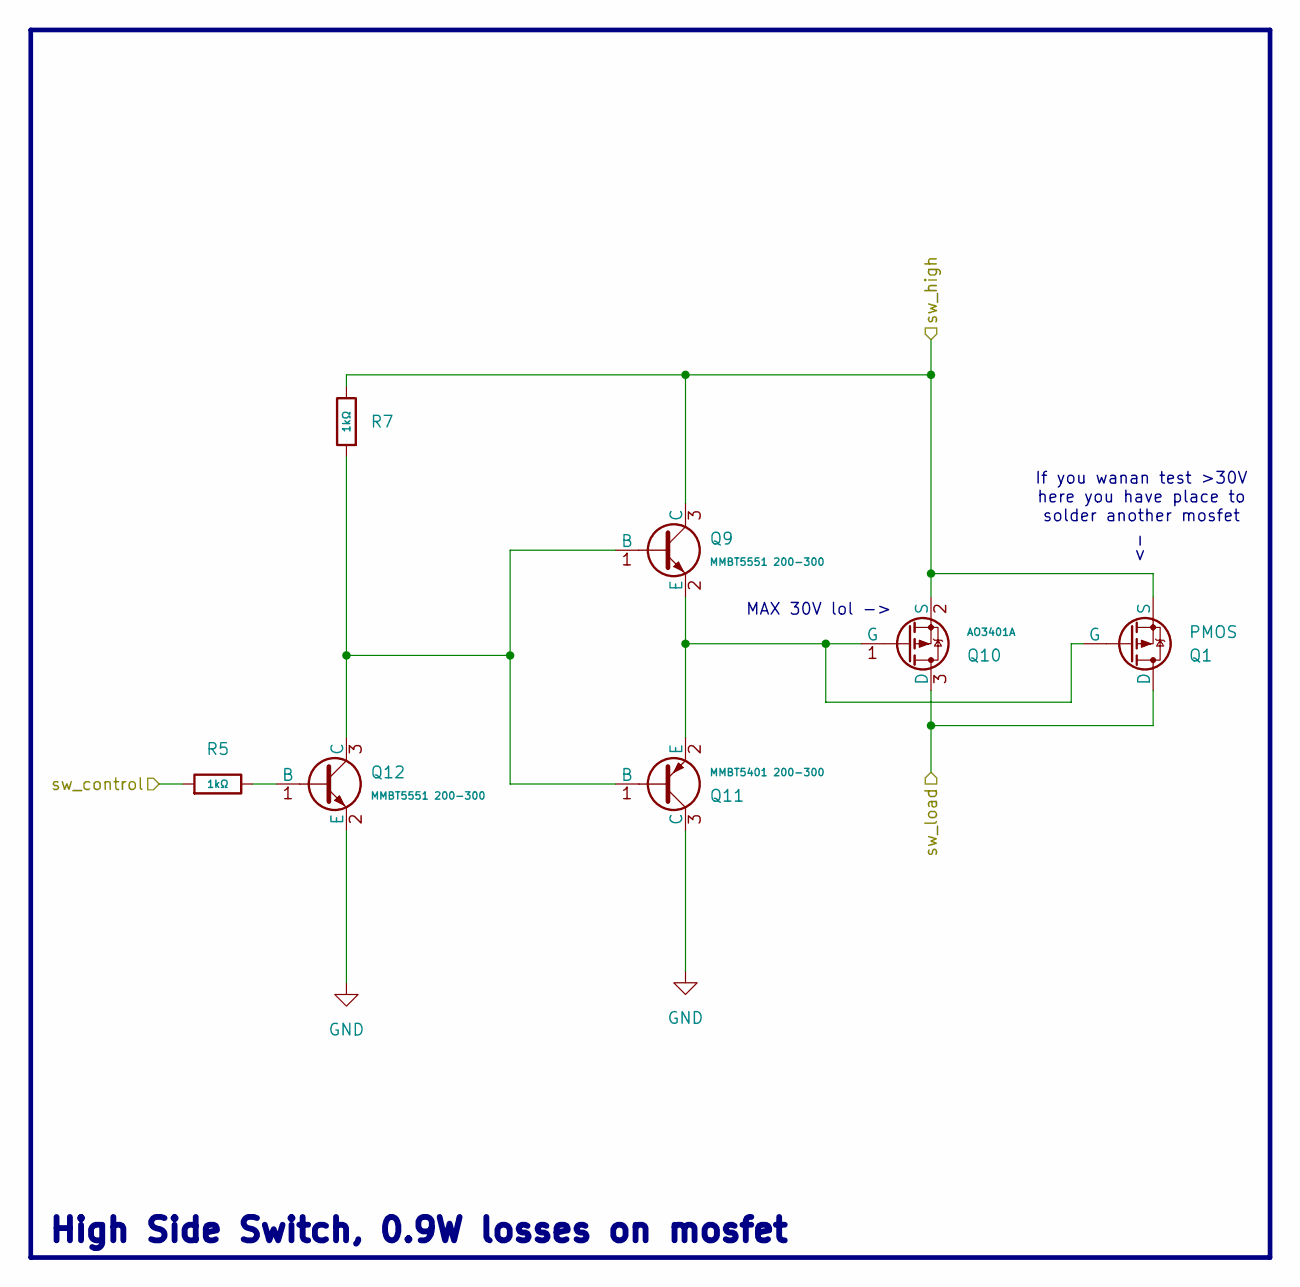
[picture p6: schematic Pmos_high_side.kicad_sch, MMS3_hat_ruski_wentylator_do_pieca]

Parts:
Q1: PMOS; TO-220-3_Vertical
Q9, Q12: MMBT5551 200-300; Q_SOT-23; Part MMBT5551(RANGE:200-300); LCSC C2145
Q10: AO3401A; Q_SOT-23; Part AO3401A; LCSC C15127
Q11: MMBT5401 200-300; Q_SOT-23; Part MMBT5401(RANGE:200-300); LCSC C8326
R5, R7: 1kΩ; R_0603; Overload Voltage (Max) 75V; Tolerance ±1%; Part 0603WAF1001T5E; LCSC C21190

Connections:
/Boost Converter/Boost_Out: Q1.3 (S), Q9.3 (C), Q10.2 (S), R7.2; also elsewhere on the board
/CN_MOT_VCC: Q1.1 (D), Q10.3 (D); also elsewhere on the board
/PWM_Mosfet_gate: R5.1; also elsewhere on the board
GND: Q11.3 (C), Q12.2 (E); also elsewhere on the board
unnamed: Q1.2 (G), Q9.2 (E), Q10.1 (G), Q11.2 (E)
unnamed: Q9.1 (B), Q11.1 (B), Q12.3 (C), R7.1
unnamed: Q12.1 (B), R5.2

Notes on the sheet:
If you wanan test >30V here you have place to solder another mosfet
MAX 30V lol ->
High Side Switch, 0.9W losses on mosfet

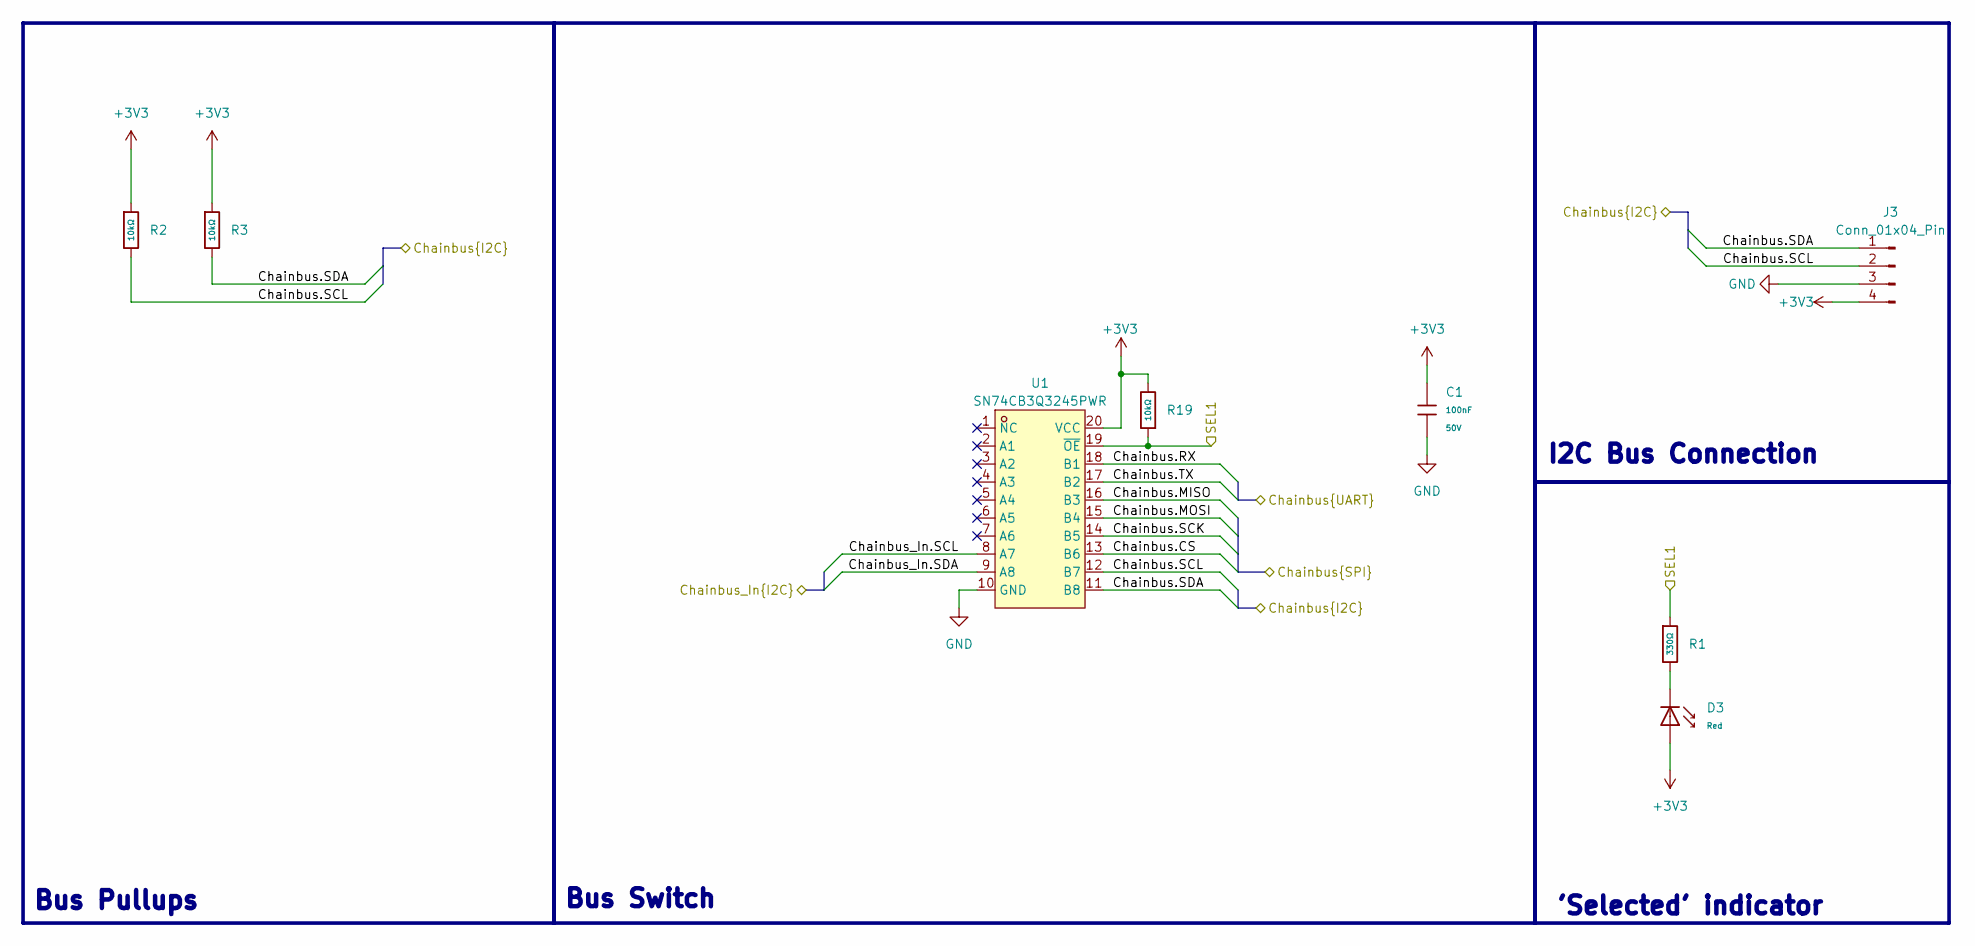
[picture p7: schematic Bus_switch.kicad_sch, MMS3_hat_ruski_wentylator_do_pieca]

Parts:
C1: 100nF; C_0603; Voltage Rated 50V; Tolerance ±10%; Part CC0603KRX7R9BB104; LCSC C14663
D3: Red; D_0603; Part KT-0603R; LCSC C2286
J3: Conn_01x04_Pin; PinHeader_1x04_P2.54mm_Vertical
R1: 330Ω; R_0402; Overload Voltage (Max) 50V; Tolerance ±1%; Part 0402WGF3300TCE; LCSC C25104
R2, R3: 10kΩ; R_0603; Overload Voltage (Max) 75V; Tolerance ±1%; Part 0603WAF1002T5E; LCSC C25804
R19: 10kΩ; R_0402; Overload Voltage (Max) 50V; Tolerance ±1%; Part 0402WGF1002TCE; LCSC C25744
U1: SN74CB3Q3245PWR; TSSOP-20_L6.5-W4.4-P0.65-LS6.4-BL; MPN SN74CB3Q3245PWR; LCSC Part C470961

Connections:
+3V3: C1.1, D3.2, J3.4, R2.1, R3.1, R19.2, U1.20 (VCC); also elsewhere on the board
/Bus_switch/Chainbus.CS: U1.13 (B6)
/Bus_switch/Chainbus.MISO: U1.16 (B3)
/Bus_switch/Chainbus.MOSI: U1.15 (B4)
/Bus_switch/Chainbus.RX: U1.18 (B1)
/Bus_switch/Chainbus.SCK: U1.14 (B5)
/Bus_switch/Chainbus.SCL: J3.2, R2.2, U1.12 (B7); also elsewhere on the board
/Bus_switch/Chainbus.SDA: J3.1, R3.2, U1.11 (B8); also elsewhere on the board
/Bus_switch/Chainbus.TX: U1.17 (B2)
/Bus_switch/Chainbus_In.SCL: U1.8 (A7); also elsewhere on the board
/Bus_switch/Chainbus_In.SDA: U1.9 (A8); also elsewhere on the board
/Bus_switch/SEL1: R1.1, R19.1, U1.19 (~OE); also elsewhere on the board
GND: C1.2, J3.3, U1.10 (GND); also elsewhere on the board
unnamed: D3.1, R1.2

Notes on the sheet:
Bus Switch
'Selected' indicator
Bus Pullups
I2C Bus Connection

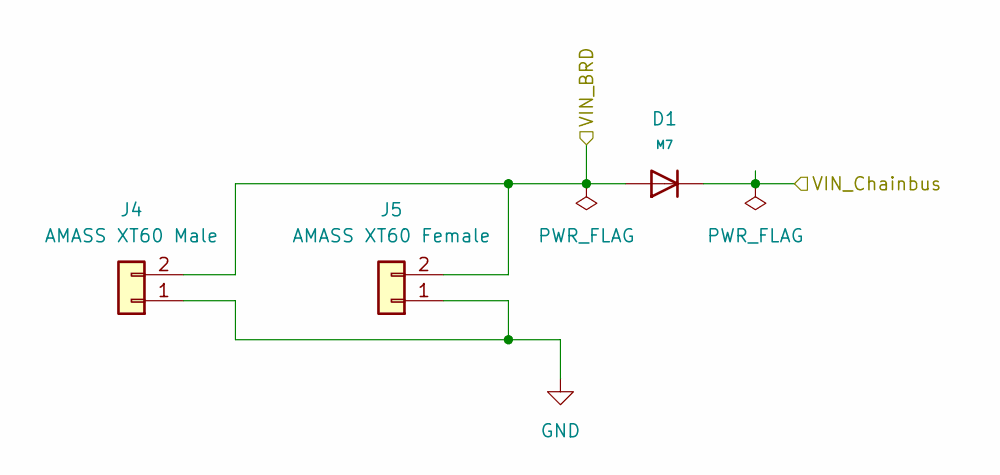
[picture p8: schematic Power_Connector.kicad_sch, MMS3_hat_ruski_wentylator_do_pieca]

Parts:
D1: M7; D_SMA; Forward Voltage (Vf@If) 1.1V@1A; Reverse Voltage (Vr) 1kV; Part M7; LCSC C95872
J4: AMASS XT60 Male; AMASS_XT60PW-M_1x02_P7.20mm_Horizontal; LCSC C98732
J5: AMASS XT60 Female; AMASS_XT60PW-F_1x02_P7.20mm_Horizontal; LCSC C428722

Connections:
/Boost Converter/Boost_In: D1.2, J4.2, J5.2; also elsewhere on the board
BRD_VIN: D1.1; also elsewhere on the board
GND: J4.1, J5.1; also elsewhere on the board

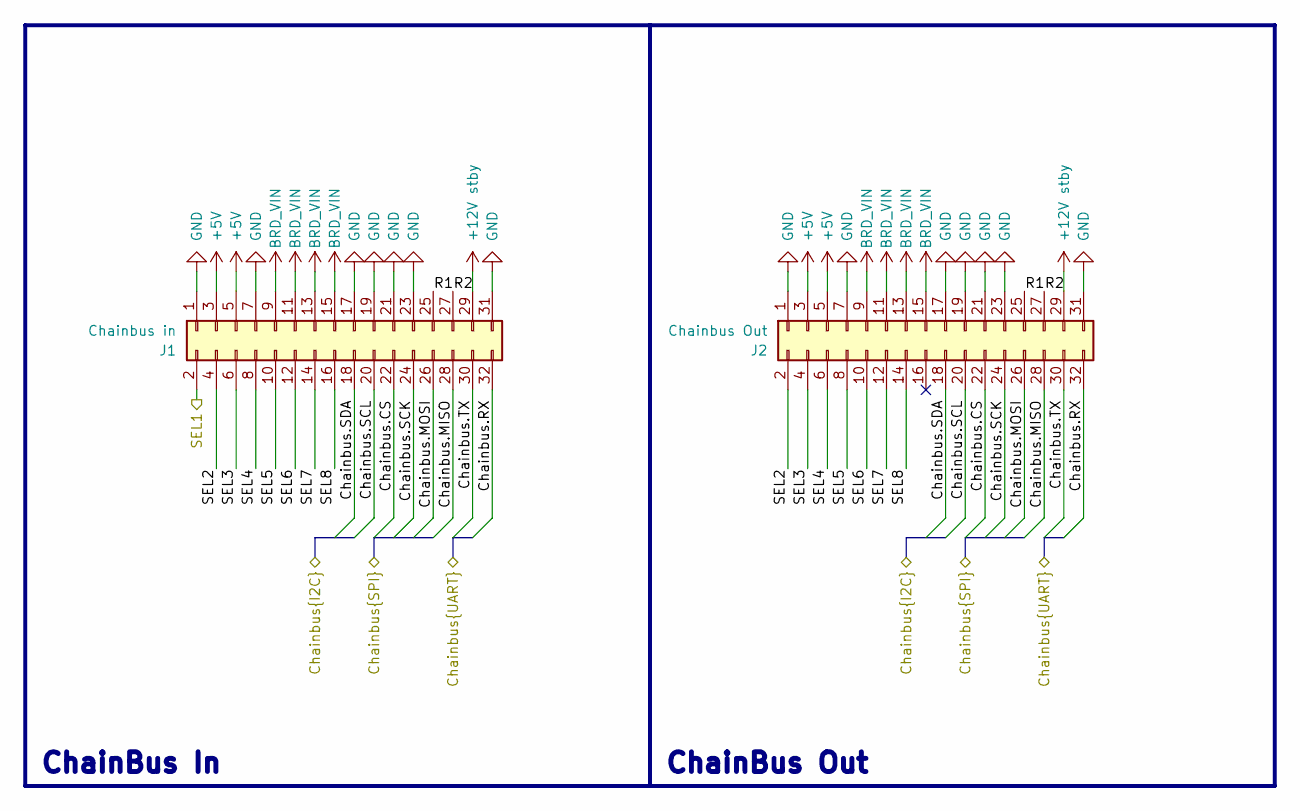
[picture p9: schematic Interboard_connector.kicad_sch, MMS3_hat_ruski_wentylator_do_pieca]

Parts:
J1: Chainbus in; PinHeader_2x16_P2.54mm_Vertical_SMD
J2: Chainbus Out; PinSocket_2x16_P2.54mm_Vertical_SMD

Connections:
+5V: J1.3, J1.5, J2.3, J2.5; also elsewhere on the board
+12V stby: J1.29, J2.29
/Bus_switch/Chainbus_In.SCL: J1.20, J2.20; also elsewhere on the board
/Bus_switch/Chainbus_In.SDA: J1.18, J2.18; also elsewhere on the board
/Bus_switch/SEL1: J1.2; also elsewhere on the board
/Interboard_connector/Chainbus.CS: J1.22, J2.22
/Interboard_connector/Chainbus.MISO: J1.28, J2.28
/Interboard_connector/Chainbus.MOSI: J1.26, J2.26
/Interboard_connector/Chainbus.RX: J1.32, J2.32
/Interboard_connector/Chainbus.SCK: J1.24, J2.24
/Interboard_connector/Chainbus.TX: J1.30, J2.30
/Interboard_connector/R1: J1.25, J2.25
/Interboard_connector/R2: J1.27, J2.27
/Interboard_connector/SEL2: J1.4, J2.2
/Interboard_connector/SEL3: J1.6, J2.4
/Interboard_connector/SEL4: J1.8, J2.6
/Interboard_connector/SEL5: J1.10, J2.8
/Interboard_connector/SEL6: J1.12, J2.10
/Interboard_connector/SEL7: J1.14, J2.12
/Interboard_connector/SEL8: J1.16, J2.14
BRD_VIN: J1.9, J1.11, J1.13, J1.15, J2.9, J2.11, J2.13, J2.15; also elsewhere on the board
GND: J1.1, J1.7, J1.17, J1.19, J1.21, J1.23, J1.31, J2.1, J2.7, J2.17, J2.19, J2.21, J2.23, J2.31; also elsewhere on the board

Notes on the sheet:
ChainBus In
ChainBus Out

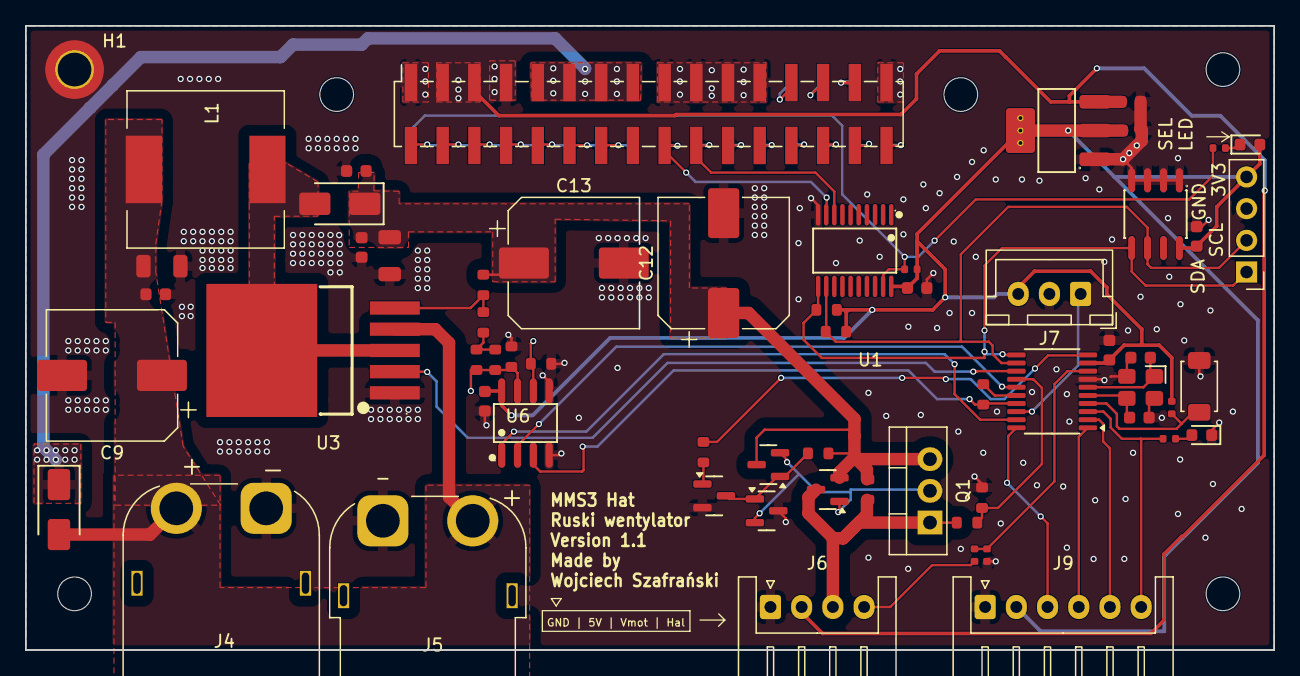
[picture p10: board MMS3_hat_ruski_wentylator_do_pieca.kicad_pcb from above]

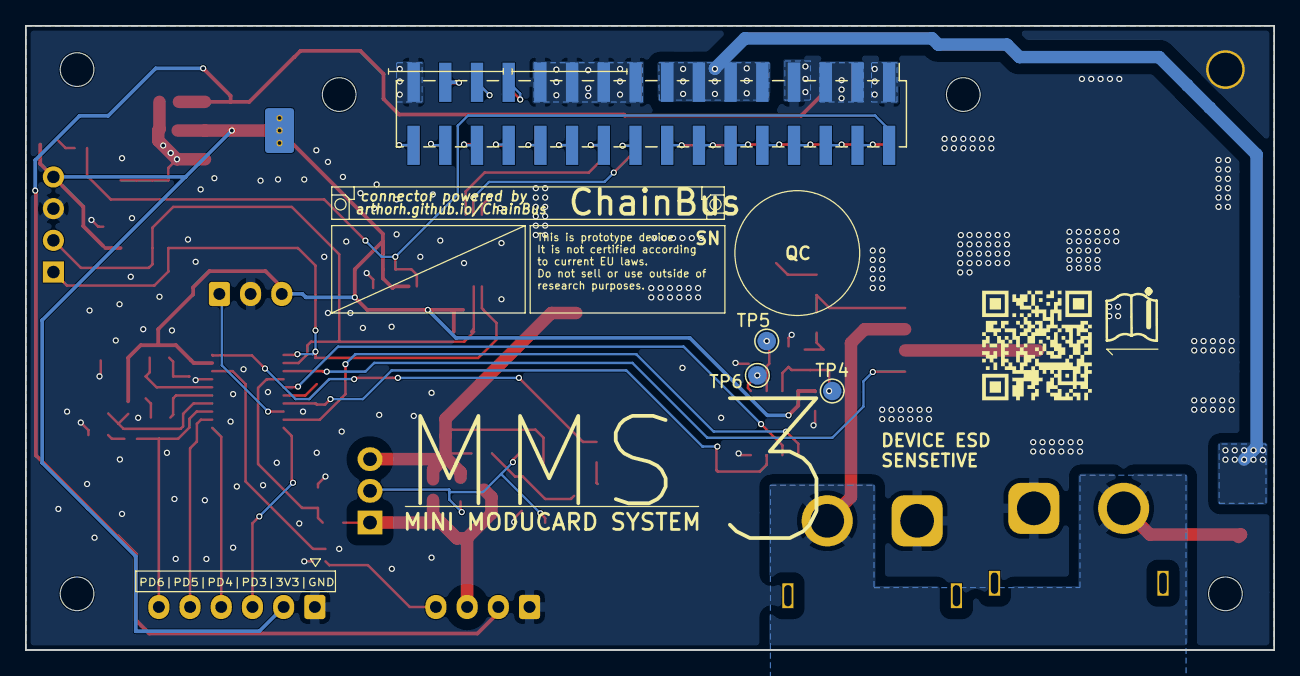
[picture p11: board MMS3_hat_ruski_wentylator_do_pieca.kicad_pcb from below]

Board: 2 copper layers, 100.0 x 50.0 mm, 71 parts (4 on the bottom side), 55 nets.

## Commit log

2026-04-29 finished schematic
    [Boost_Converter.kicad_sch, Bus_switch.kicad_sch, CH32V003.kicad_sch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]
2026-05-01 inital layout
    [Boost_Converter.kicad_sch, Bus_switch.kicad_sch, MMS3_hat_ruski_wentylator_do_pieca.kicad_pcb]
2026-05-04 commit before removing all the diodes :"
    [Boost_Converter.kicad_sch, Bus_switch.kicad_sch, CH32V003.kicad_sch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]
2026-05-04 finished routing
    [Boost_Converter.kicad_sch, CH32V003.kicad_sch, MMS3_hat_ruski_wentylator_do_pieca.kicad_pcb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]
2026-05-05 minor fixes etc
    [BOM-MMS3_hat_ruski_wentylator_do_pieca.csv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]
2026-06-08 BREAKING: updated CH32v003 programming pinout
    [Boost_Converter.kicad_sch, Bus_switch.kicad_sch, CH32V003.kicad_sch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]
2026-06-10 added documentation
    [BOM-MMS3_hat_ruski_wentylator_do_pieca.csv, Boost_Converter.kicad_sch, Bus_switch.kicad_sch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]
2026-08-14 added more readme
    [BOM-MMS3_hat_ruski_wentylator_do_pieca.csv, CH32V003.kicad_sch, Interboard_connector.kicad_sch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]
2026-10-03 V1.1, fixed SDA SCL Swap
    [BOM-MMS3_hat_ruski_wentylator_do_pieca.csv, Boost_Converter.kicad_sch, Bus_switch.kicad_sch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]
2026-10-03 V1.1 generated production files
    [Boost_Converter.kicad_sch, Bus_switch.kicad_sch, CH32V003.kicad_sch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]
